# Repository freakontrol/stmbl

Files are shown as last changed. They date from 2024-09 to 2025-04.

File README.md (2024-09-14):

 

DISCLAIMER
===

THE AUTHORS OF THIS SOFTWARE ACCEPT ABSOLUTELY NO LIABILITY FOR
ANY HARM OR LOSS RESULTING FROM ITS USE.  IT IS _EXTREMELY_ UNWISE
TO RELY ON SOFTWARE ALONE FOR SAFETY.  Any machinery capable of
harming persons must have provisions for completely removing power
from all motors, etc, before persons enter any danger area.  All
machinery must be designed to comply with local and national safety
codes, and the authors of this software can not, and do not, take
any responsibility for such compliance.

This software is released under the GPLv3.

STMBL
=====

This Repository is a fork of the original project [STMBL](https://github.com/rene-dev/stmbl), an open-source servo drive designed for Retrofitting CNC machines and Robots. It supports Industrial AC and DC servos.

You can read the [documentation](https://freakontrol.github.io/stmbl/) to learn more about this project.

We are proposing a new revision of the project making significant improvements and updates:

- H-bridge
- Power connectors
- Bulk Capacitor
- Heat dissipation components and case
- Other obsolete components

 

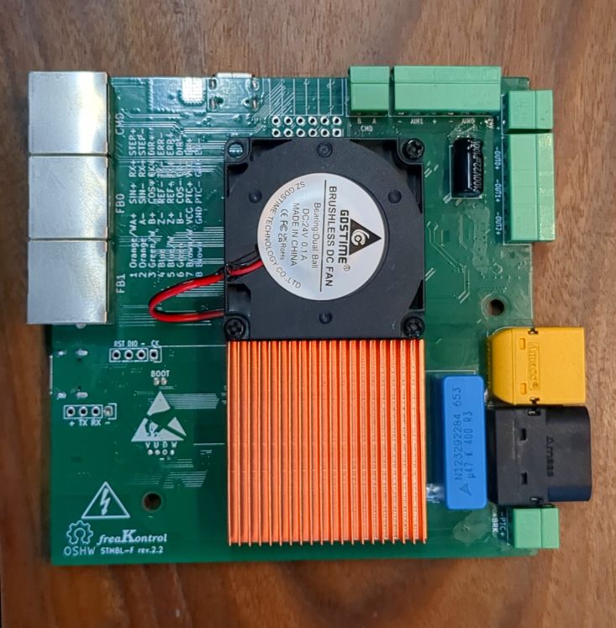
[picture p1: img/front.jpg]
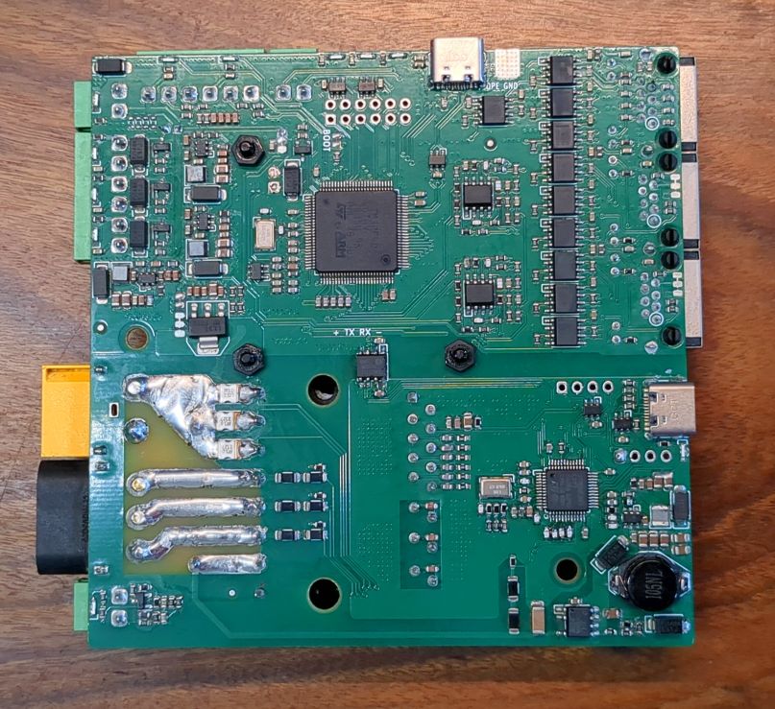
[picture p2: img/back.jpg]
  

## H-Bridge
First we needed to replace the original and obsolete H-bridge IRAM256 with a more powerful and easily available one.
We chose the [Infineon IKCM30F60GD](https://www.mouser.it/datasheet/2/196/Infineon_IKCM30F60GD_DataSheet_v02_05_EN-3361791.pdf) capable of peak output currents up to 60Amps instead of 30 of the original bridge.

## Upgrading Power connectors
During our tests with earlier prototypes we noticed that the original power connectors overheated and even got damaged when the board drove big loads.

 

So we decided to replace power connectors, both HV DC input and 3 Phase output with golden plated XT60PW and MR60PW connectors from Amass®, designed for high current up to 60Amps.

## Bulk Capacitor

We have relocated big bulk capacitors outside in a rectifier module as close as possible to the drives. 
Instead internally we kept a more compact MKP Polypropylene snubber capacitor for decoupling the bridge HV power supply.

 

## Heat dissipation components and case

We also optimized heat dissipation components and layout, reducing overall volume by half compared to the original design.

 
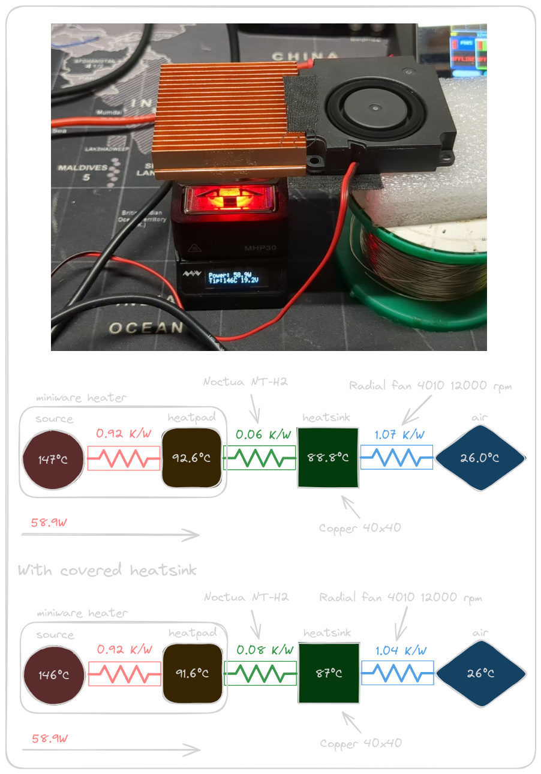
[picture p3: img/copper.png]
 

## Other obsolete components

there were several other components that have been replaced because they have become obsolete:

- ACT4088US-T (DC/DC converter) replaced with [RT8259GE](https://www.mouser.it/datasheet/2/1458/DS8259_03-3104661.pdf) from Richtek.
- With DC/DC converters, the power inductors have also been updated to:
    - [ME3220-472MLC 4.7uH ](https://www.mouser.it/ProductDetail/994-ME3220-472MLC)
    - [ME3220-682MLC 6.8uH](https://www.mouser.it/ProductDetail/994-ME3220-682MLC)
    - [ME3220-103KLC 10uH](https://www.mouser.it/ProductDetail/994-ME3220-103KLC)
- ZLDO1117G33TA (LDO 3.3V 1A) replaced with its new version [LDL1117S33R](https://www.mouser.it/ProductDetail/511-LDL1117S33R) from STMicroelettronics
- both microUSB connectors have been updated to the more modern USBc

* * * 
If you want to get a prototype of this board contact us [here](https://matrix.to/#/@stmbl:freakontrol.com).  
"Buy Me A Coffee" (https://www.buymeacoffee.com/freakontrol)

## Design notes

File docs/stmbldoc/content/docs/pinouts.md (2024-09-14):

---
title: "Pinouts"
weight: 5
# bookFlatSection: false
# bookToc: true
# bookHidden: false
# bookCollapseSection: false
# bookComments: false
# bookSearchExclude: false
---

## Pinouts

Interfaces:

* Mesa SmartSerial = full-duplex UART
* Encoder = QUAD
* Resolver = SIN/COS
* SSI, BiSS, EnDAT = half-duplex SPI
* Misu 02 = half-duplex UART
* Sanyo Denki = half-duplex UART
* Hyperface = SIN/COS + half-duplex UART

### Command connector wiring:

| Pin | Color | Smart Serial | Step/Dir | Quadrature  |
|-----|---|---|---|---|
| 1 | Orange Stripe | RX+ | Step+ | A+ |
| 2 | Orange | RX- | Step- | A- |
| 3 | Green Stripe | TX+ | Dir+ | B+ |
| 4 | Blue | | Err- | |
| 5 | Blue Stripe | | Err+ | |
| 6 | Green | TX- | Dir- | B- |
| 7 | Brown Stripe | | Enbl+ | |
| 8 | Brown | | Enbl- | |

### Feedback connector wiring - encoders etc

| Pin | Color | Resolver | Encoder | 1Vpp | UVW | Mitsubishi | Sanyo-Denki | Yaskawa | Omron  |
|-----|---|---|---|---|---|---|---|---|---|
| 1 | Orange Stripe | Sin+ | A+ | Sin+ | U+ | | | | |
| 2 | Orange | Sin- | A- | Sin- | U- | | | | |
| 3 | Green Stripe | Cos+ | B+ | Cos+ | V+ | | | | |
| 4 | Blue | Ref- | Z- | | W- | 2 | Blue | 6 | 4 |
| 5 | Blue Stripe | Ref+ | Z+ | | W+ | 1 | Brown | 5 | 7 |
| 6 | Green | Cos- | B- | Cos- | V- | | | | |
| 7 | Brown Stripe | AIN | VCC | VCC | VCC | VCC | Red | 1 | 6 |
| 8 | Brown | GND | GND | GND | GND | GND | Black | 2 | 3 |

### Connector wiring - serial protocols

| Pin | Color | RS485 | RS422 | UART | USART | UART HD  | USART HD | SPI | SPI HD |
|-----|---|---|---|---|---|---|---|---|---|
| 1 | Orange Stripe | | A | RX+ | RX+ | | | MISO+ | CS+ |
| 2 | Orange | | B | RX- | RX- | | | MISO- | CS- |
| 3 | Green Stripe | | | | CLK+ | | CLK+ | CLK+ | CLK+ |
| 4 | Blue | B | Z | TX- | TX- | TX/RX- | TX/RX- | MOSI- | MOSI- |
| 5 | Blue Stripe | A | Y | TX+ | TX+ | TX/RX+ | TX/RX+ | MOSI+ | MOSI+ |
| 6 | Green | | | | CLK- | | CLK- | CLK- | CLK- |
| 7 | Brown Stripe | VCC | VCC | VCC | VCC | VCC | VCC | VCC | VCC |
| 8 | Brown | GND | GND | GND | GND | GND | GND | GND | GND |

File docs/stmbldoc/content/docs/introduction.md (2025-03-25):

---
title: "Introduction"
weight: 1
# bookFlatSection: true
bookToc: true
# bookHidden: false
# bookCollapseSection: true
# bookComments: true
# bookSearchExclude: false
---

# STMBL Introduction Guide

## Description

STMBL is a motor drive controlled by the STM32 microprocessor. It can power motors of up to 2.2kW and up to around 380V DC bus voltage. The name "STMBL" is based on the combination of the STM32 microprocessor and BrushLess motor. However, the drive is also capable of powering AC induction or DC motors. The hardware is also capable of driving 3-phase stepper motors.

The drive is configurable for a wide range of command and feedback types through a hardware abstraction layer (HAL) analogous to that used by [LinuxCNC](http://linuxcnc.org/docs/2.7/html/hal/intro.html).

Currently supported command interfaces are:

* Mesa Smart-Serial  
* Quadrature, Step-Dir, Dir-Step, Up-Down ([enc cmd](/docs/hal_components/enc_cmd.md))  
* Usb Python interface  

Encoder power is 5V by default but 12V can be selected by jumper pads on the PCB.

In addition to motor control and dual feedback, each STMBL drive has two +/-30V analogue inputs and three 24V / 2A digital outputs.

To use the STMBL, you will need to:

* connect your command, feedback, and motor to STMBL using **suitable cables**.
* [Flash the firmware](/docs/introduction/#flashing-firmware)
* configure the drive for your motor using [Servoterm](/docs/getting_started/servoterm.md)
  * configure your [Feedback interface](/docs/getting_started/feedback.md)
  * find the correct [Motor parameters](/docs/getting_started/motor.md) for your motor
  * configure your [Command interface](/docs/getting_started/cmd.md)

## Anatomy of the STMBL

The STMBL consists of two separate PCBs that are made as one then assembled and split to be connected in the manner shown below. The vertical (top) board is the low-voltage (LV) board, and this handles the command, feedback, and configuration tasks. The STM32F405 microprocessor is in charge of these tasks.

The lower board is the high-voltage (HV) board, and this is where the power driver is situated. The only connection between the two boards is a serial connection through a 2.5kV isolation IC. To make this possible, there is a second STM32 chip on the lower board. This is an STM32F303 and is referred to as "F3" in the remainder of this document. The processor on the upper board is referred to as "F4".

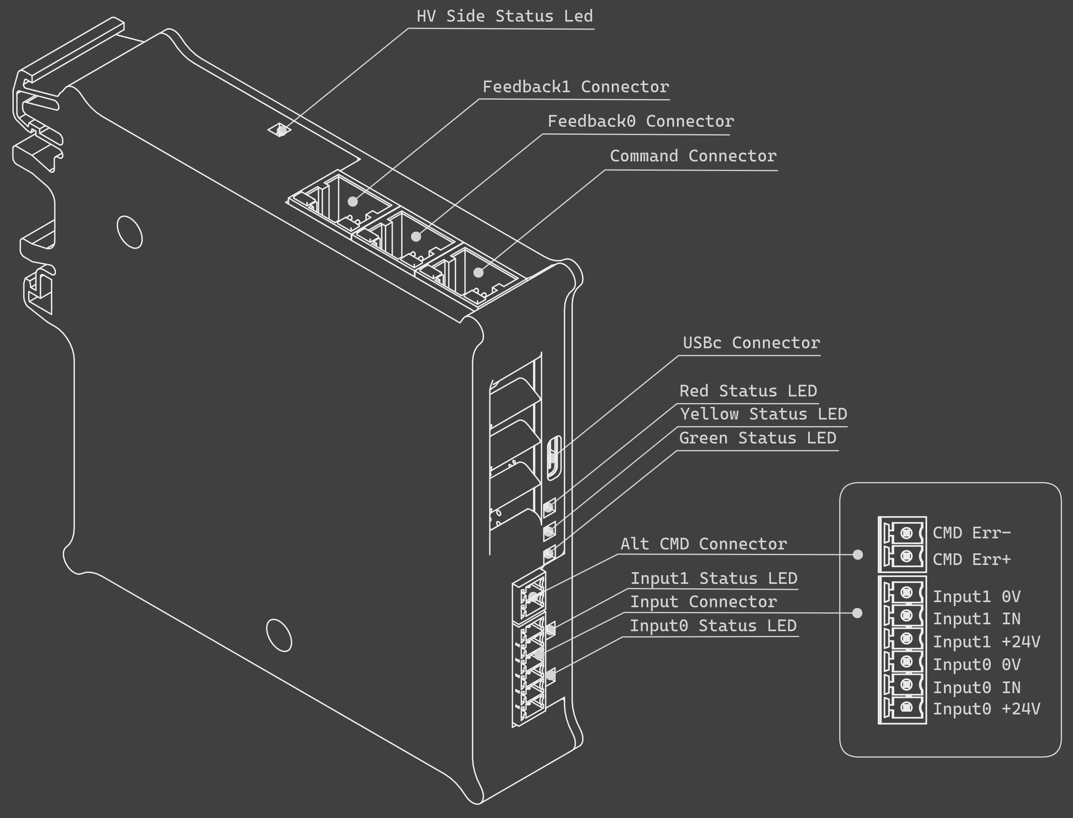
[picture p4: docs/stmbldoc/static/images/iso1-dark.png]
STMBL Anatomy


Logic power to the LV board should be 24V. A green LED will light adjacent to the socket when power is supplied.

{{% hint warning %}}
The LV board is safe up to about 26V but take care that 0V is common with the PC GND before connecting a USB cable.  
{{% /hint %}}

Motor power should be 30 to 350V, though the logic parts of the HV board may work at 24V for firmware flashing etc. Again, a green LED adjacent to the connector confirms that the board is powered-up.  

{{% hint warning %}}
The HV and LV boards are isolated in normal use but it is easy to accidentally connect them. One way to do this is via USB cables which can easily tie GND lines together through the setup PC.  
{{% /hint %}}  

{{% hint danger %}}
 It is imperative that the HV board should be powered from an isolated, low voltage supply when flashing firmware.
{{% /hint %}}  

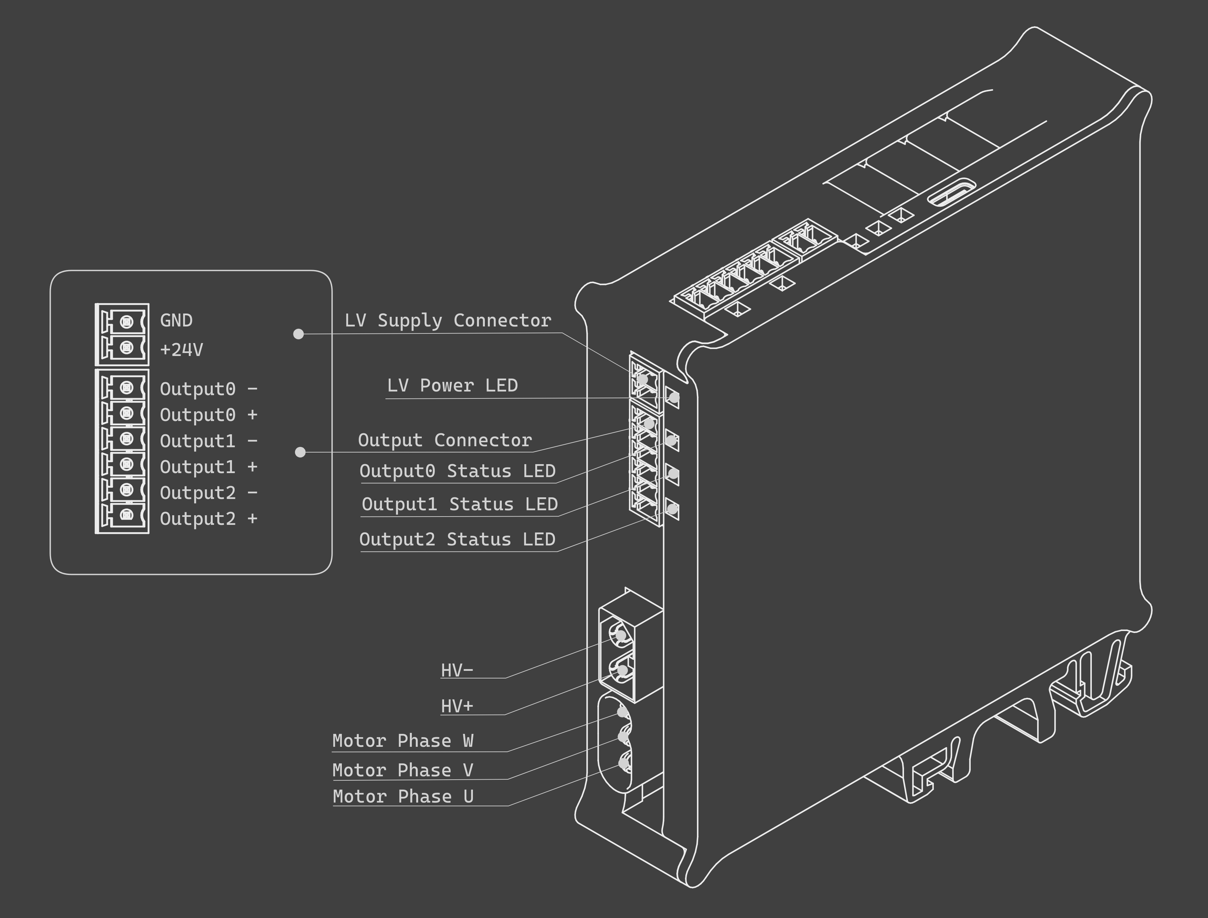
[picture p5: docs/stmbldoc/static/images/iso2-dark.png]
STMBL Connectors


The command and feedback connectors use standard 8P8C (RJ45) connectors and standard CAT5 or CAT6 cables can be conveniently used. To connect to cables with larger conductors than supported by CAT5, it is possible to use, for example, [Industrial CAT6a](https://octopart.com/j00026a2001-telegärtner-24873031) connectors which can accept core wires up to 1.6mm and overall cable diameters up to 9.0mm.

Feedback 0 will typically be the encoder or resolver mounted on the motor, and feedback 1 can be used to connect either Hall sensors for initial commutation or (potentially) scales mounted directly to the axes. See the [Pinouts](/docs/getting_started/pinouts) section of this document for pin assignments and typical wiring color codes.

The 6-way socket below the 24V logic power connector contains the three digital outputs. These are current-sinking (switch-to-GND) and each is adjacent to a 24V supply pin. DIO0 (nearest the top) is the one that is typically used to operate the holding brake on motors so-equipped.

On the top of the drive are two analog inputs, with 0V and 24V on either side to that an active sensors can be connected. These are typically used as variable-threshold digital inputs and are used, for example, for axis limit switches. However, it is relatively simple to configure them for other uses in the HAL.

Three LEDs on top of the unit indicate drive status. Red displays error codes (using [Blink Codes](/docs/errors/)). Amber indicates that all is well but the drive is not enabled, and green shows that the drive is active and operating normally. If no LEDs on the top of the board are illuminated, and the green power LEDs near the power connectors _are_ illuminated, then it is probably necessary to [flash the firmware](/docs/introduction/#flashing-firmware). If there are LEDs lit on top of the drive, then it is probably safe to assume that firmware is loaded.

## HAL (Hardware Abstraction Layer)

STMBL uses a data flow graph to configure the drive for different types of motor, feedback, and operation mode. This is conceptually similar to the HAL in [LinuxCNC](http://linuxcnc.org/docs/2.7/html/hal/intro.html), but the format and commands are different. Also, all pins are floating point so no data conversion is needed.  

Here is the graphical representation of the default configuration for the LV board and for the HV board

{{< zoomable-image src="/stmbl/graph/f4_festo_graph.dot.svg" alt="Low Voltage default hal config" >}}

{{< zoomable-image src="/stmbl/graph/hvf3_graph.dot.svg" alt="High Voltage default hal config" >}}  

An Application called [Servoterm](/docs/getting_started/servoterm/) is used to interact with the HAL interface and configure the drive. You will need to install and launch this before it is possible to configure the STMBL.

STMBL HAL configuration does not use any commands other than the = sign and the [Servoterm Commands](/docs/getting_started/servoterm/#servoterm-commands).

Assuming that there is already a motor connected to the drive and that the drive is powered up, the Servoterm display should already be indicating the motor position feedback. Rotating the motor shaft by hand might produce something like:

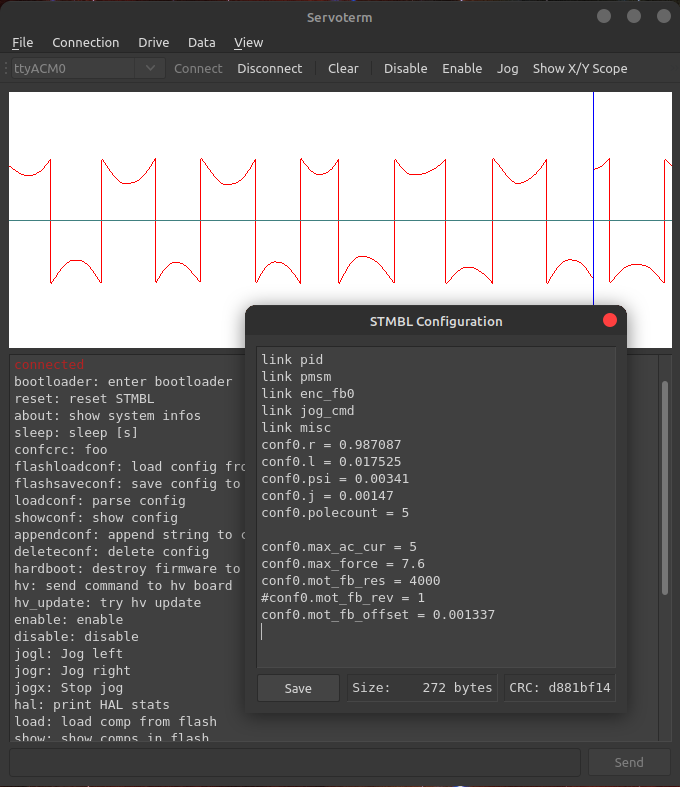
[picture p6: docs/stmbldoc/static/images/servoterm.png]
Servoterm Display


Though it equally well might not if the configuration is set up for a resolver and the motor has an encoder. It should be possible to make the motor turn at this point without any further configuration. The commands that follow will set the hv0 module up to simply rotate the motor open-loop in direct-mode (like a stepper motor) with an excitation current of 0.5A. This should be safe for most motors that the STMBL is a good match for, but you should choose your own value. For an explanation of direct and quadrature current, see the section on [Motor Basics](/docs/getting_started/motor/#motor-basics).

```
hv0.pos = sim0.vel
hv0.d_cmd = 0.5
hv0.en = 1
```

The rotation speed can be altered by changing the sim0 frequency:

```
sim0.freq = 5
```

STMBL HAL contains a number of components that have built-in linking behavior.

### Resolvers

Resolver phase - Setting the phase is very important to get resolver output. 'res0.phase = X' sets the phase. The number is between 0 and 1. Set for the highest output.

Resolver speed - In motor drives, resolver speed is typically 1. One rotation of the resolver equals one rotation of the motor. You will want to add these settings to the config so that the drive powers up with the settings as default.

### Motor pole count / setting motor feedback offset

Motor pole count in data sheets is often a total pole count rather than STMBL required 'pole pair' count. This is easy to see when running the com_test: type 'link com_test'. This should start the motor turning slowly in open loop, while displaying on the graph. Ideally, the green and black lines will match closely. If they are not the same speed (same number of peaks), then the motor poles setting is wrong. 'conf0.polecount' can be set without stopping the test. Set it till the number of green and black peaks are the same. Now the peaks may be offset on the graph. 'conf0.motor_fb_offset' will set this. Adjust this number till the black and green lines match. You'll want to add these settings to the config so the drive starts with these defaults.

### Jogging test

If you set the jogging checkbox at the top of ServoTerm and then enable the drive with: 'fault0.en = 1', using the left and right cursor keys on the keyboard can be used to jog the motor. The escape key will disable the drive quickly if something is not quite right. If there is a fault, then you will need to toggle the enable pin to 0 and back to 1 again. If the drive oscillates, try adjusting the 'conf0.j' setting for inertia.

### Drive the motor with a sine wave

1. Connect it `rev0.in = sim0.msin`
2. Set amplitude `sim0.amp = 1` (in rad)
3. Set frequency `sim0.freq = 0.5` (in Hz)
4. Enable `fault0.en = 1`

### Or constant velocity

1. Connect it `rev0.in = sim0.vel`
2. Set frequency `sim0.freq = 0.5` (in Hz)
3. Enable `fault0.en = 1`

Pressing Esc at any time will disable the drive. To reenable, press reset or type `fault0.en = 0` followed by `fault0.en = 1`.

### Components/templates/config list and examples  

You can find the list of components, template and configs in the Hal components, templates and configs section.  

## Flashing Firmware

### Requirements to build firmware

The GCC cross-compiler for Arm: gcc-arm-none-eabi-gcc [https://launchpad.net/gcc-arm-embedded/+download](https://launchpad.net/gcc-arm-embedded/+download) You will also need the STMBL source code, available from [https://github.com/freakontrol/stmbl](https://github.com/freakontrol/stmbl). You can either clone this as a [git](https://git-scm.com/) archive or just download a current snapshot as a zip file. In order for the STMBL Makefiles to be able to find the gcc binaries, you may need to create the file toolchain-user.mak to point to the correct folder and version number.

### Requirements to flash firmware

The STM32 chips have a built-in ROM bootloader, this means that it should be impossible to "brick" the boards. Each of the two CPUs in the STMBL drive needs both a dedicated bootloader to start the STMBL firmware and the firmware itself.

#### Linux/Unix

To flash the boards with USB, you will need the dfu-utils package [http://dfu-util.sourceforge.net](http://dfu-util.sourceforge.net). To flash the boards with a stlink programmer over SWD, you will need the stlink package [https://github.com/texane/stlink](https://github.com/texane/stlink)

#### Windows

You will need the STM Virtual Comport driver to connect with Servoterm [http://www.st.com/content/st_com/en/products/development-tools/software-development-tools/stm32-software-development-tools/stm32-utilities/stsw-stm32102.html](http://www.st.com/content/st_com/en/products/development-tools/software-development-tools/stm32-software-development-tools/stm32-utilities/stsw-stm32102.html) And the DfuSe USB device firmware upgrade STMicroelectronics extension to flash the firmware over USB [https://www.st.com/en/development-tools/stsw-stm32080.html](https://www.st.com/en/development-tools/stsw-stm32080.html)

### Checking for Existing Firmware - F4 board

Before flashing firmware, it is worth trying to figure out if your board is completely blank or has been pre-flashed with a bootloader or firmware. If the board will connect with Servoterm, then it already has a firmware and STMBL bootloader. "about" will show the firmware information of the F4 board. "hv about" will give the same information about the F3 board. Go to the [Updating Firmware](/docs/introduction/#updating-firmware) section to flash new firmware. If the board lights any LEDs other than the green power-good ones near to the power input connectors, then there is likely to already be a firmware installed. Go to the [Updating Firmware](/docs/introduction/#updating-firmware) section if you need to update the firmware. If the board is powered with 24V to the LV board and connected with USB to a PC, then it will report as "STMBL Virtual ComPort:" in the Apple System Profiler, "ID 0483:5740 STMicroelectronics STM32F407" in lsusb in Linux, and "STMBL Virtual COM Port" in the Windows device manager if there is a full firmware + STM32 bootloader installed. If the board shows "STM32 BOOTLOADER" (Mac), "0483:df11 STMicroelectronics STM Device in DFU Mode" (Linus lsusb), or "STM32 BOOTLOADER" (Windows Device Manager) when powered up (without using the boot pads), then this indicates that it already has an STMBL bootloader. (though no harm is done by re-flashing this) If the LV board does not show up at all on the USB bus, then attempt to put it in ROM boot mode by shorting the boot pads together while connecting the 24V. You should see "STM32 Bootlader" (Mac), "STMicroelectronics STM Device in DFU Mode" (Linux lsusb), or "STM32 BOOTLOADER" (Windows Device Manager) In this case, you will need to flash both the STMBL bootloader and the STMBL firmware. Go to the [Flashing the LV board with no bootloader](/docs/introduction/#flashing-the-lv-board-with-no-bootloader) section.

### Checking for existing firmware - F3 board

With 24V to the F3 board and with the F4 board _unpowered_, look at the red LED under the fan, near the USB connector. If the HV board has both an STMBL bootloader and an STMBL Firmware installed, then it will illuminate only the green power LED and will flash the red LED slowly to indicate no comms with the F4 board (which is why this check should be done with the F4 board unpowered). Go to the [Updating Firmware](/docs/introduction/#updating-firmware) section in this scenario. If the F3 board does not flash the red LED when the F4 is unpowered, then there is no bootloader and no firmware flashed. Go to the [Flashing the HV board with no bootloader](/docs/introduction/#flashing-the-hv-board-with-no-bootloader) section. If the F3 board has only a bootloader flashed and no or broken firmware, then the red LED will flash rapidly. Use the instructions in [Updating Firmware](/docs/introduction/#updating-firmware) in this case. The boards can also be flashed with a SWD programmer, but that process is not documented here. It can be convenient to flash the boards to test them before separating the halves and before installing the IRAM module and bus capacitors if you have a self-built or part-assembled board. Precompiled Binary versions of the firmware can be downloaded from [https://github.com/freakontrol/stmbl/releases](https://github.com/freakontrol/stmbl/releases) When compiling from the source code, firmware flashing is handled by specifying a makefile target for each of the firmware sections.

### Updating Firmware

The firmware on both the F3 and F4 board can be updated through the F4 USB port and without access to the boot pads. Connect 24V to both the F3 and F4 boards. In the source software folder, type `git pull` to get the latest software version. Type `make clean` to ensure that all files are freshened. Type `make` followed by `make binall` to create the binary files to be flashed. Type `make btburn` to program the F4 firmware and transfer a copy of the F3 software or type `make all_btburn` to program the F4 firmware + bootloader and transfer a copy of the F3 software 
{{% hint warning %}}
this will overwrite your config 
{{% /hint %}}  
There should then be a quantity of text output culminating with a progress bar like:

```
Downloading to address = 0x08000000, size = 2756
Download [=========================] 100% 2756 bytes
```

You can now re-connect with Servoterm and check the firmware version with `about`. Updating the F3 firmware is done via Servoterm using the `hv_update` command. This should give output similar to:

```
hv_update: SEND_TO_BOOTLOADER
hv_update: ERASE_FLASH
hv_update: SEND_APP
hv_update: status: 4%
...
hv_update: status: 95%
hv_update: CRC_CHECK
hv_update: status: 100%
hv_update: FLASH_SUCCESS
hv_update: status: 100%
hv_update: SLAVE_IN_APP
```

If this fails multiple times, go to the [Flashing the HV board with no bootloader](/docs/introduction/#flashing-the-hv-board-with-no-bootloader) section.

### Flashing the LV board with no bootloader

To flash the initial bootloader and firmware, it is necessary to put the STM32 CPU into ROM bootloader mode. You do this by shorting together the two pads marked "boot" on the LV board while connecting the 24V supply. This is a bit of a fiddle but should only need to be done once when the board is first built. For the exact location of these pads, see the illustration in the [Anatomy of the STMBL](/docs/introduction/#anatomy-of-the-stmbl) section. Typically, a small screwdriver can be used for this purpose. At this point, the board should appear as an "STM32 Bootloader" in the USB tree of the attached PC. Follow the [Updating Firmware](/docs/introduction/#updating-firmware) instructions and use the `make all_btburn` command.

### Flashing the HV board with no bootloader

Connect the USB cable to the HV board and short the boot pads on the HV board while connecting 24V to the HV input. To put it into bootloader mode. Again, it should appear in the USB device tree. Follow the [Updating Firmware](/docs/introduction/#updating-firmware) instructions but use the `make f3_all_btburn` command.

## linuxcnc

STMBL supports Mesa Smartserial to communicate with LinuxCNC. [http://linuxcnc.org/docs/html/man/man9/sserial.9.html](http://linuxcnc.org/docs/html/man/man9/sserial.9.html)

[https://www.youtube.com/watch?v=5CKMrOy0ZXk](https://www.youtube.com/watch?v=5CKMrOy0ZXk)

### STMBL config

At the end of your STMBL config, load sserial:

```
link sserial
```

Set the scale:

```
linrev0.scale = 5
```

#### Example: HAL config for Position mode with Position feedback

This is an example for one axis, Mesa 5i25 and one STMBL board, added to a .hal file in a machine config:

```
# This is an example for linuxcnc hal in position mode for the x-axis:
net xposcmd joint.0.motor-pos-cmd => hm2_5i25.0.stbl.0.0.pos_cmd
net xvelcmd joint.0.vel-cmd => hm2_5i25.0.stbl.0.0.vel_cmd
net xposfb joint.0.motor-pos-fb <= hm2_5i25.0.stbl.0.0.pos_fb
net xenable joint.0.amp-enable-out => hm2_5i25.0.stbl.0.0.enable
net xfault joint.0.amp-fault-in <= hm2_5i25.0.stbl.0.0.fault
net xindex joint.0.index-enable <=> hm2_5i25.0.stbl.0.0.index_enable
```

#### Example: Full Machine Config with STMBL boards, Mesa 7i80, Mesa 7i77, Analog Outputs, Encoder Inputs

See [https://github.com/aShure/cnc-configs/tree/master/justinbieber](https://github.com/aShure/cnc-configs/tree/master/justinbieber)

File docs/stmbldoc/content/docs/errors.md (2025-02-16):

---
title: "Errors"
weight: 7
# bookFlatSection: false
# bookToc: true
# bookHidden: false
# bookCollapseSection: false
# bookComments: false
# bookSearchExclude: false
---

# Blink Codes

## LV Side

### Normal Operation
   * No Error (Green LED on top illuminated. Good!)
   * Drive disabled (Yellow LED on top. Drive ready to go but disabled.)
   * Autophasing (Green and Yellow)
### Errors
   * Soft fault, resettable (Red LED blinks according to the list below)
   * Hard fault, bad! (All LEDs on top blink.)

Count the number of blinks of the red LED. Each number indicates a different class of faults.

 | LED Blink Times | Error                                 | Possible Solution                                          |
   |-----------------|-------------------------------------|------------------------------------------------------------|
   | 1               | Command Error                       | Common during setup. Only really relevant to smart-serial   |
   | 2               | Motor Feedback Error                | Verify motor feedback connections.         |
   | 3               | Commutation Feedback Error          | Check commutation feedback connections and configuration.    |
   | 4               | Joint Feedback Error                | Ensure joint feedback is properly connected and configured.|
   | 5               | Position Error                      | Review positioning mechanisms and settings.                |
   | 6               | Saturation Error                    | Adjust parameters to avoid saturation.                     |
   | 7               | Motor temperature high              | Check for overheating issues or motor ptc misconfiguration.   |
   | 8               | HV Side serial CRC Error           | Ensure data integrity during communication with the side.|
   | 9               | HV Side comms Timeout Error        | HV side is not powered or programmed correctly.             |
   | 10              | HV Side over-temperature           | Check the fan, air intake/output obstruction or dust in the heatsink.  |
   | 11              | HV Voltage out of range             | Check if power supply is stable and if the dynamic braking circuit is working. |
   | 12              | HV Side Fault                      | Investigate specific faults reported by the HV side.      |
   | 13              | HV current offset fault             | Damaged F3 micro ADC?            |
   | 14              | HV Overcurrent RMS                  | Reduce average current consumption to stay within limits.  |
   | 15              | HV Overcurrent Peak                 | Limit peak current spikes to prevent overcurrent issues.   |
   | 16              | HV Overcurrent HW                   | The motor power size is too high (or the bridge is broken) |

## HV Side

### Normal operation
   * Green LED at power input
### Errors
   * Red LED blinks fast - Bootloader but no or broken firmware
   * Red LED blinks slow - No communication with F4
   * Red LED does not blink _AND_ F4 not plugged in - No firmware or bootloader

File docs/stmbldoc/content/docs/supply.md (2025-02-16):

---
title: "Supply"
weight: 6
# bookFlatSection: false
# bookToc: true
# bookHidden: false
# bookCollapseSection: false
# bookComments: false
# bookSearchExclude: false
---

 # Power Supply Requirements for STMBL Board

The STMBL board is designed to operate with a specific range of voltage and current for its various components. Understanding these requirements is crucial for proper operation and safety. This page provides an overview of the power supply requirements for the STMBL board, including information about the big electrolitic capacitors needed in the power supply close to the HV board.

## Power Supply Specifications

The following table summarizes the power supply specifications for the STMBL board:

### PCB Version 5

| Connector | Abs. MIN | MIN | TYP | MAX | Abs. MAX | Unit | Note |
|---|---|-----|-----|-----|---|---|---|
| 24V | 0 | 15  | 24  | 25  | 26 | V | |
| 24V | | | 0.2 | 3 | 6 | A | 1 |
| HV | 0 | 24  | 320 | 380 | 400 | V | |
| HV | -28 | -17 | | 17  | 28 | A | 2 |
| CMD | -7 | 0 | | 5 | 12 | V | |
| CMD | -250 | -50 | | 50  | 250 | mA | |
| FB VPP | 0 | 0 | | 12  | 24 | V | |
| FB VPP | 0 | 0 | 500 | 1000| 1500 | mA | |
| FB diff.  | -7 | 0 | | 5 | 12 | V | |
| FB diff.  | | -1.2| | +1.2| | Vpp  | 3 |
| FB | -250 | -50 | | 50  | 250 | mA | |
| output | 0 | 0 | | 24  | 26 | V | |
| output | 0 | 0 | | 1 | 2 | A | |
| input | -36 | -24 | | 24  | 36 | V | |
| IO | 0 | 0 | | 5 | 5 | V | |
| UVW | 0 | 0 | | 380 | 400 | V | |
| UVW | -30 | -58 | | 58  | 60 | A | |
| UVW avg.  | | -27 | | 27  | | A | 2 |

*Note 1: Depends on brake, fan and encoder consumption*  
*Note 2: Depends on PCB and driver cooling*  
*Note 3: For analog input*

## Big Electrolitic Capacitors

The STMBL board requires the use of big electrolitic capacitors in its power supply, particularly close to the HV board. These capacitors are essential for filtering and stabilizing the high-voltage power supply, ensuring smooth operation and reducing electrical noise. The specific capacitance values may vary depending on the exact application and motor load. It is recommended to consult the STMBL documentation or a qualified engineer for the most accurate capacitor selection.

## Safety Considerations

When working with high-voltage components like the STMBL board, it is crucial to prioritize safety. Always follow proper installation and usage guidelines, and ensure that all connections are secure and properly insulated. Never attempt to operate the board without the necessary power supply or motor load connected. In case of any doubts or concerns about the power supply requirements, consult a qualified engineer or refer to the official STMBL documentation for further guidance.

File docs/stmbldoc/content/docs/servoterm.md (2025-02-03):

---
title: "Servoterm"
weight: 3
# bookFlatSection: false
# bookToc: true
# bookHidden: false
# bookCollapseSection: false
# bookComments: false
# bookSearchExclude: false
---

# Servoterm

Servoterm (servo terminal) provides an interface which allows editing of the drive HAL configuration. It also provides a rolling graphical representation of any chosen parameter in the HAL, which can be a great aid to tuning and motor setup.

Servoterm is now available as a C++ application. You can download it from [this GitHub repository](https://github.com/STMBL/QtServoterm).

## Installation

To install Servoterm, follow these steps:

1. Clone the repository:
   ```sh
   git clone https://github.com/STMBL/QtServoterm.git
   ```

2. Navigate to the project directory:
   ```sh
   cd QtServoterm
   ```

3. Build the application using qmake and make:
   ```sh
   qmake
   make
   ```

4. Run the application:
   ```sh
   ./Servoterm
   ```

## Connecting to STMBL

To connect to the STMBL, you will need a mini-USB B cable. 
{{% hint danger %}}
Be sure that the 24V PSU is floating or shares a ground reference with the PC.  
(Maybe even check the voltage between the connector and socket before inserting the plug.)
{{% /hint %}}  
You can then click the "connect" button and you should get something like the image below.  

## Servoterm Interface

Taking the buttons from left to right:

* Connect / Disconnect - Should be fairly self-evident
* Clear - simply clears the screen
* Reset - Reenables the drive and clears faults. Does not reset the STMBL. To do that type the [Servoterm Commands](#servoterm-commands), `reset`
* Capture - Allows the output of the graphs to be saved and exported as CSV. First click starts the recording, second click stops and saves the file.
* Jog - when ticked the left-right arrow keys on the keyboard can be used to jog the motor.
* Trigger - stops the graph plot until the trigger condition is met.
* Trigger Status Indicator - not a button
* Edit Config - Brings up a sub-window in which the basic system config can be edited.

Other than the buttons described above, the remainder of Servoterm (and the STMBL HAL) is controlled by a command-line interface at the bottom. Servoterm uses the up and down arrow keys to scroll through previous commands, but there is no tab-completion. This is mainly described in the [HAL](#hal-hardware-abstraction-layer) section of this document. The graphing display is controlled by the "term0" interface. Typing `term0` at the prompt will show output similar to:

Servoterm Terminal Interface

The first two entries are internal information about the HAL component and can be ignored for now. The next 8 lines say what internal signal each of the wave plots is connected to. In this case, wave0 (the black one) is connected to a sim signal, in this case, the sine wave. (as you might have guessed, typing "sim0" will show you the parameters of the simulated signals.) To connect wave1 (red) to the sawtooth output (which simulates both encoder feedback and a position command for steady rotation), then simply type `term0.wave1 = sim0.vel`. Each wave has an associated offset and gain parameter that can be used to adjust vertical scale and position. The `term0.send_step` parameter functions like the time-base of an oscilloscope.

## Servoterm Commands

The Servoterm command list can be obtained at the command line by using the `help` command. Commands to be used by the user:

* bootloader: enter bootloader
* reset: reset STMBL
* about: show system infos
* help: print this
* link: load config template
* hal: print HAL stats
* hv_update: update the F3 firmware
* show_config: show config templates
* show: show comps in flash
* list: show comp instances
* hv FOOBAR XYZ: send "FOOBAR XYZ" to the HV board

Commands for internal use:

* confcrc: Shows the CRC checksum of the loaded config.
* flashloadconf: load config from flash
* flashsaveconf: save config to flash
* loadconf: parse config
* showconf: show config - pressing the `Edit config` button is better.
* appendconf: append string to config - also redundant with the config editor
* deleteconf: delete config
* load: load comp from flash
* start: start rt system
* stop: stop rt system
* fault: trigger fault

## Servoterm Connection Problems

If you encounter connection issues, ensure that your serial setup is correct. Here are some steps to troubleshoot:

1. **Check Serial Port**: Ensure that the correct serial port is selected in Servoterm.
2. **Ground Reference**: Make sure that the 24V PSU is floating or shares a ground reference with the PC.
3. **USB Cable**: Use a good quality mini-USB B cable to connect the STMBL to your computer.

Linux/Mac? Add your username to the dialout group to be able to access the com ports. If you have used the Arduino IDE before, this is probably already set:

```
sudo usermod -a -G dialout username

```

Linux udev rules:

```
SUBSYSTEM=="usb", ACTION!="add", GOTO="objdev_rules_end"
#stmbl
ATTR{idVendor}=="0483", ATTR{idProduct}=="5740", ENV{ID_MM_DEVICE_IGNORE}="1", GROUP="users", MODE="0666"
#ST USB bootloader
ATTR{idVendor}=="0483", ATTR{idProduct}=="df11", GROUP="users", MODE="0666"
LABEL="objdev_rules_end"

```

If you get AT commands showing up in servoterm some application is sending commands to the virtual serial port despite the `ENV{ID_MM_DEVICE_IGNORE}="1"` above. For example on xfce with debian 10, ModemManager may need to be stopped with `systemctl disable ModemManager.service` or removed with `sudo apt-get purge modemmanager`

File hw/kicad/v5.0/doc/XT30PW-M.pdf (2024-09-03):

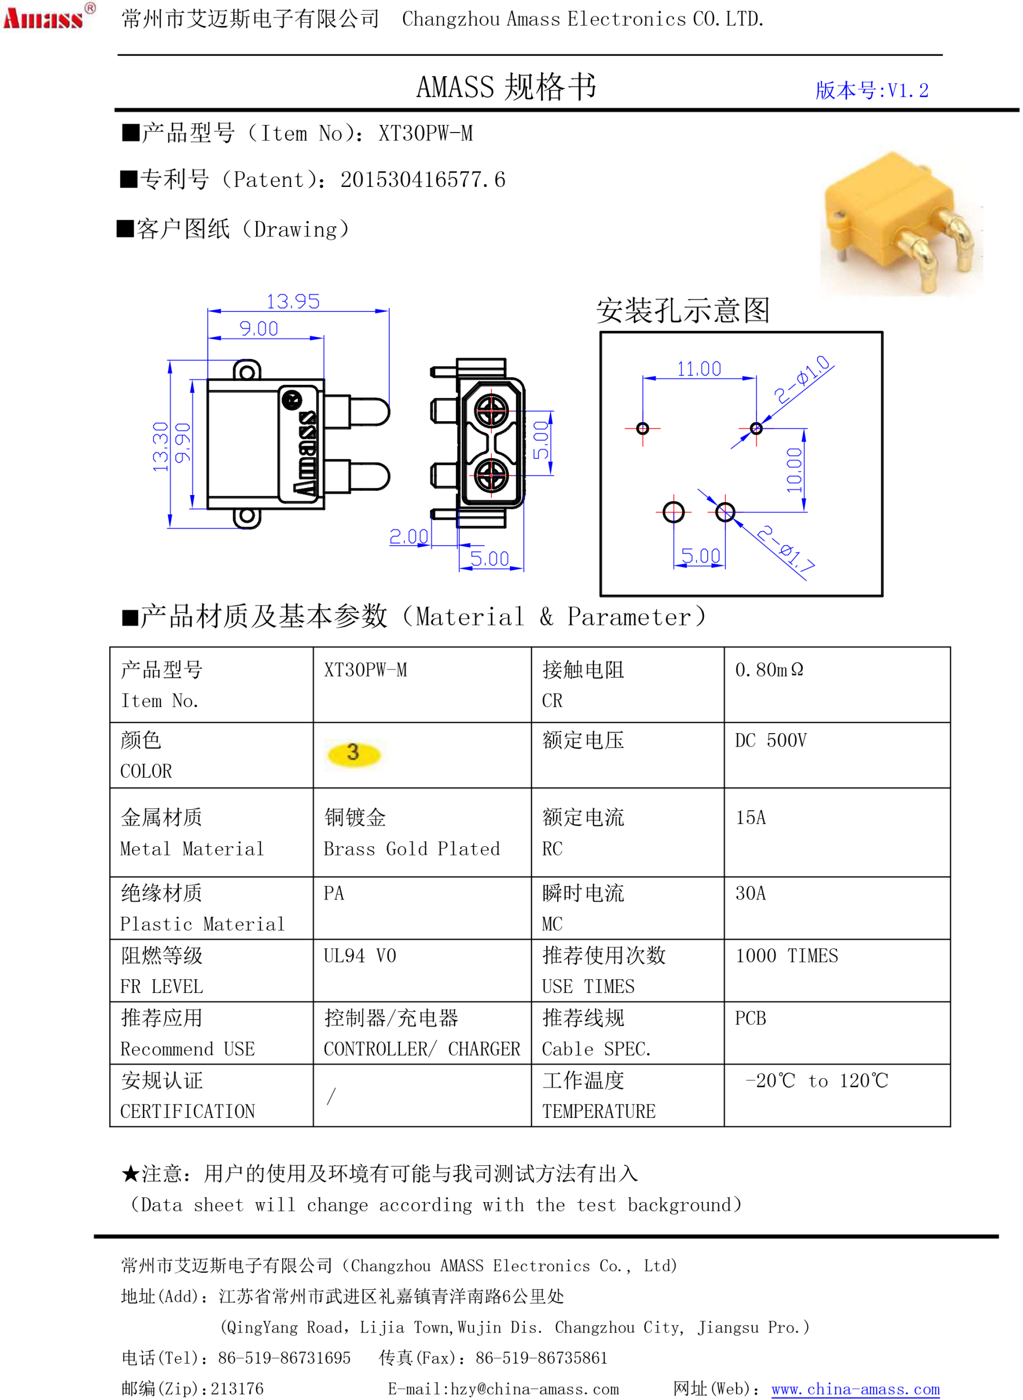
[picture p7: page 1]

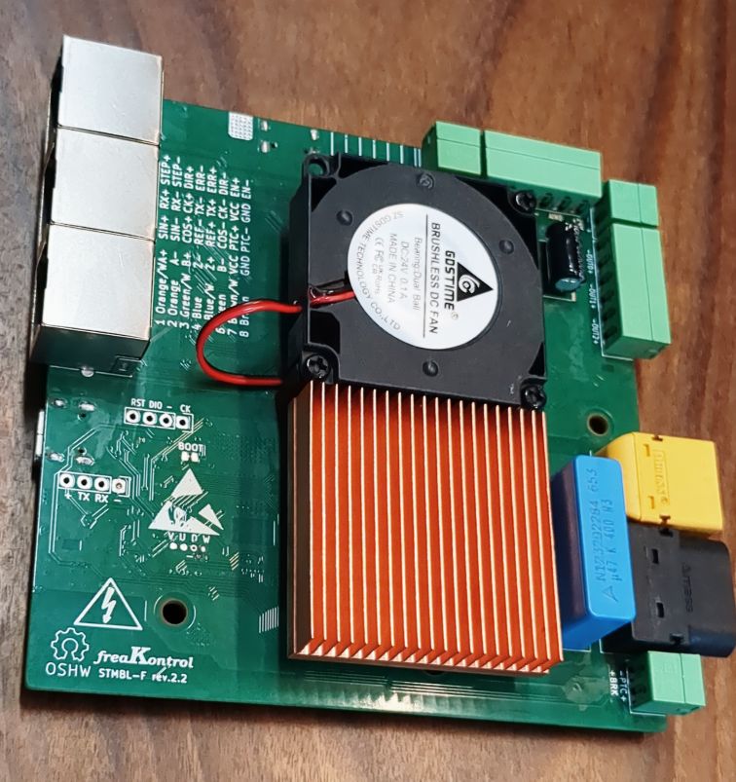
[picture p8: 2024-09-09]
img/front2.jpg

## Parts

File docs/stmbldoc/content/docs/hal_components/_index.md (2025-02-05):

---
bookCollapseSection: true
weight: 2
redirect_to: "/docs/hal_components/ac/"
---

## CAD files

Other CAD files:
mechanics/stmbl_case_industrial.FCStd

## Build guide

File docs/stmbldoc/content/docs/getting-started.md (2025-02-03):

---
title: "Getting Started"
weight: -1
# bookFlatSection: true
bookToc: true
# bookHidden: false
# bookCollapseSection: true
# bookComments: true
# bookSearchExclude: false
---

# STMBL Getting Started Guide

## Description

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

Currently supported command interfaces are:

* Mesa Smart-Serial
* Step-Dir
* Quadrature
* Serial

+/-10V control is not supported, though the hardware capability exists.

Currently supported feedback interfaces are:

* Encoder
* Resolver
* sin/cos 1vpp
* Hall sensors
* Mitsubishi absolute encoder
* Yaskawa absolute encoder
* Sanyo Denki absolute encoder
* Fanuc serial encoder

The hardware has the capability to support other protocols like:

* EnDat
* BiSS
* SSI
* Modbus
* Profibus
* Hiperface
* CANopen

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

To use the STMBL, you will need to:

* connect your command, feedback, and motor to STMBL using **suitable cables**.
* [Flash the firmware](getting-started.md/#flashing-firmware)
* configure the drive for your motor using [Servoterm](servoterm.md)
  * configure your [Feedback interface](configuration/feedback.md)
  * find the correct [Motor parameters](configuration/motor.md) for your motor
  * configure your [Command interface](configuration/cmd.md)

## Anatomy of the STMBL

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

STMBL Anatomy

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

STMBL Connectors

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

Feedback 0 will typically be the encoder or resolver mounted on the motor, and feedback 1 can be used to connect either Hall sensors for initial commutation or (potentially) scales mounted directly to the axes. See the [Pinouts](#pinouts) section of this document for pin assignments and typical wiring color codes.

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

Three LEDs on top of the unit indicate drive status. Red displays error codes (using [Blink Codes](#blink-codes)). Amber indicates that all is well but the drive is not enabled, and green shows that the drive is active and operating normally. If no LEDs on the top of the board are illuminated, and the green power LEDs near the power connectors _are_ illuminated, then it is probably necessary to [flash the firmware](#flashing-firmware). If there are LEDs lit on top of the drive, then it is probably safe to assume that firmware is loaded.

## HAL (Hardware Abstraction Layer)

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

An Application called [Servoterm](#servoterm) is used to interact with the HAL interface and configure the drive. You will need to install and launch this before it is possible to configure the STMBL.

STMBL HAL configuration does not use any commands other than the = sign and the [Servoterm Commands](#servoterm-commands).

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

Servoterm Display

Though it equally well might not if the configuration is set up for a resolver and the motor has an encoder. It should be possible to make the motor turn at this point without any further configuration. The commands that follow will set the hv0 module up to simply rotate the motor open-loop in direct-mode (like a stepper motor) with an excitation current of 0.5A. This should be safe for most motors that the STMBL is a good match for, but you should choose your own value. For an explanation of direct and quadrature current, see the section on [Motor Basics](#motor-basics).

```
hv0.pos = sim0.vel
hv0.d_cmd = 0.5
hv0.en = 1
```

The rotation speed can be altered by changing the sim0 frequency:

```
sim0.freq = 5
```

STMBL HAL contains a number of components that have built-in linking behavior.

### Resolvers

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

### Motor pole count / setting motor feedback offset

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

### Jogging test

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

### Drive the motor with a sine wave

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

### Or constant velocity

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

## Flashing Firmware

### Requirements to build firmware

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

### Requirements to flash firmware

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

#### Linux/Unix

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

#### Windows

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

### Checking for Existing Firmware - F4 board

Before flashing firmware, it is worth trying to figure out if your board is completely blank or has been pre-flashed with a bootloader or firmware. If the board will connect with Servoterm, then it already has a firmware and STMBL bootloader. "about" will show the firmware information of the F4 board. "hv about" will give the same information about the F3 board. Go to the [Updating Firmware](#updating-firmware) section to flash new firmware. If the board lights any LEDs other than the green power-good ones near to the power input connectors, then there is likely to already be a firmware installed. Go to the [Updating Firmware](#updating-firmware) section if you need to update the firmware. If the board is powered with 24V to the LV board and connected with USB to a PC, then it will report as "STMBL Virtual ComPort:" in the Apple System Profiler, "ID 0483:5740 STMicroelectronics STM32F407" in lsusb in Linux, and "STMBL Virtual COM Port" in the Windows device manager if there is a full firmware + STM32 bootloader installed. If the board shows "STM32 BOOTLOADER" (Mac), "0483:df11 STMicroelectronics STM Device in DFU Mode" (Linus lsusb), or "STM32 BOOTLOADER" (Windows Device Manager) when powered up (without using the boot pads), then this indicates that it already has an STMBL bootloader. (though no harm is done by re-flashing this) If the LV board does not show up at all on the USB bus, then attempt to put it in ROM boot mode by shorting the boot pads together while connecting the 24V. You should see "STM32 Bootlader" (Mac), "STMicroelectronics STM Device in DFU Mode" (Linux lsusb), or "STM32 BOOTLOADER" (Windows Device Manager) In this case, you will need to flash both the STMBL bootloader and the STMBL firmware. Go to the [Flashing the LV board with no bootloader](#flashing-the-lv-board-with-no-bootloader) section.

### Checking for existing firmware - F3 board

With 24V to the F3 board and with the F4 board _unpowered_, look at the red LED under the fan, near the USB connector. If the HV board has both an STMBL bootloader and an STMBL Firmware installed, then it will illuminate only the green power LED and will flash the red LED slowly to indicate no comms with the F4 board (which is why this check should be done with the F4 board unpowered). Go to the [Updating Firmware](#updating-firmware) section in this scenario. If the F3 board does not flash the red LED when the F4 is unpowered, then there is no bootloader and no firmware flashed. Go to the [Flashing the HV board with no bootloader](#flashing-the-hv-board-with-no-bootloader) section. If the F3 board has only a bootloader flashed and no or broken firmware, then the red LED will flash rapidly. Use the instructions in [Updating Firmware](#updating-firmware) in this case. The boards can also be flashed with a SWD programmer, but that process is not documented here. It can be convenient to flash the boards to test them before separating the halves and before installing the IRAM module and bus capacitors if you have a self-built or part-assembled board. Precompiled Binary versions of the firmware can be downloaded from [https://github.com/freakontrol/stmbl/releases](https://github.com/freakontrol/stmbl/releases) When compiling from the source code, firmware flashing is handled by specifying a makefile target for each of the firmware sections.

### Updating Firmware

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

```
Downloading to address = 0x08000000, size = 2756
Download [=========================] 100% 2756 bytes
```

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

```
hv_update: SEND_TO_BOOTLOADER
hv_update: ERASE_FLASH
hv_update: SEND_APP
hv_update: status: 4%
...
hv_update: status: 95%
hv_update: CRC_CHECK
hv_update: status: 100%
hv_update: FLASH_SUCCESS
hv_update: status: 100%
hv_update: SLAVE_IN_APP
```

If this fails multiple times, go to the [Flashing the HV board with no bootloader](#flashing-the-hv-board-with-no-bootloader) section.

### Flashing the LV board with no bootloader

To flash the initial bootloader and firmware, it is necessary to put the STM32 CPU into ROM bootloader mode. You do this by shorting together the two pads marked "boot" on the LV board while connecting the 24V supply. This is a bit of a fiddle but should only need to be done once when the board is first built. For the exact location of these pads, see the illustration in the [Anatomy of the STMBL](#anatomy-of-the-stmbl) section. Typically, a small screwdriver can be used for this purpose. At this point, the board should appear as an "STM32 Bootloader" in the USB tree of the attached PC. Follow the [Updating Firmware](#updating-firmware) instructions and use the `make all_btburn` command.

### Flashing the HV board with no bootloader

Connect the USB cable to the HV board and short the boot pads on the HV board while connecting 24V to the HV input. To put it into bootloader mode. Again, it should appear in the USB device tree. Follow the [Updating Firmware](#updating-firmware) instructions but use the `make f3_all_btburn` command.

## linuxcnc

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

[https://www.youtube.com/watch?v=5CKMrOy0ZXk](https://www.youtube.com/watch?v=5CKMrOy0ZXk)

### STMBL config

At the end of your STMBL config, load sserial:

```
link sserial
```

Set the scale:

```
linrev0.scale = 5
```

#### Example: HAL config for Position mode with Position feedback

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

```
# This is an example for linuxcnc hal in position mode for the x-axis:
net xposcmd joint.0.motor-pos-cmd => hm2_5i25.0.stbl.0.0.pos_cmd
net xvelcmd joint.0.vel-cmd => hm2_5i25.0.stbl.0.0.vel_cmd
net xposfb joint.0.motor-pos-fb <= hm2_5i25.0.stbl.0.0.pos_fb
net xenable joint.0.amp-enable-out => hm2_5i25.0.stbl.0.0.enable
net xfault joint.0.amp-fault-in <= hm2_5i25.0.stbl.0.0.fault
net xindex joint.0.index-enable <=> hm2_5i25.0.stbl.0.0.index_enable
```

#### Example: Full Machine Config with STMBL boards, Mesa 7i80, Mesa 7i77, Analog Outputs, Encoder Inputs

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

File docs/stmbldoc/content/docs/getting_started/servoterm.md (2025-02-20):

---
title: "Servoterm"
weight: 2
# bookFlatSection: false
# bookToc: true
# bookHidden: false
# bookCollapseSection: false
# bookComments: false
# bookSearchExclude: false
---

# Servoterm

Servoterm (servo terminal) provides an interface which allows editing of the drive HAL configuration. It also provides a rolling graphical representation of any chosen parameter in the HAL, which can be a great aid to tuning and motor setup.

Servoterm is now available as a C++ application. You can download it from [this GitHub repository](https://github.com/STMBL/QtServoterm).  

## Installation

To install Servoterm, follow these steps:

1. Clone the repository:
   ```sh
   git clone https://github.com/STMBL/QtServoterm.git
   ```

2. Navigate to the project directory:
   ```sh
   cd QtServoterm
   ```

3. Build the application using qmake and make (you need to install first the required dependencies based on your system):
   ```sh
   qmake
   make
   ```

4. Run the application:
   ```sh
   ./Servoterm
   ```

## Connecting to STMBL

To connect to the STMBL, you will need a USB C cable. 
{{% hint danger %}}
Be sure that the 24V PSU is floating or shares a ground reference with the PC.  
(Maybe even check the voltage between the connector and socket before inserting the plug.)
{{% /hint %}}  
You can then click the "connect" button and you should get something like the image below.  

Servoterm Terminal Interface

## Servoterm Interface

Taking the buttons from left to right:

* **Connect** / **Disconnect** (Connection) - Should be fairly self-evident
* **Clear** - simply clears the screen
* **Disable** / **Enable** (Drive) - Reenables the drive and clears faults. Does not reset the STMBL. To do that type the [Servoterm Commands](/docs/getting_started/servoterm/#servoterm-commands), `reset`
* **Record** (Data) - Under Data menu, it allows the output of the graphs to be saved and exported as CSV.
* **Jog** (Drive) - when ticked the left-right arrow keys on the keyboard can be used to jog the motor.
* **Show X/Y Scope** (View) - This shows or hides the XY scope in the graph side.
* **Config** (Drive) - Brings up a sub-window in which the basic system config can be edited.

Other than the buttons described above, the remainder of Servoterm (and the STMBL HAL) is controlled by a command-line interface at the bottom. Servoterm uses the up and down arrow keys to scroll through previous commands, but there is no tab-completion. This is mainly described in the [HAL](/docs/introduction/#hal-hardware-abstraction-layer) section. The graphing display is controlled by the "term0" interface. Typing `term0` at the prompt will show output similar to:

```ini
term0.rt_prio = 16.000000
term0.frt_prio = 0.000000
term0.wave0 <= reslimit0.pos_out = 0.000000
term0.wave1 <= fb_switch0.plot_fb_pos = -0.000785
term0.wave2 <= vel0.vel = 0.000000
term0.wave3 <= vel1.vel = 0.000000
term0.wave4 = 0.000000
term0.wave5 = 0.000000
term0.wave6 = 0.000000
term0.wave7 = 0.000000
term0.offset0 = 0.000000
term0.offset1 = 0.000000
term0.offset2 = 0.000000
term0.offset3 = 0.000000
term0.offset4 = 0.000000
term0.offset5 = 0.000000
term0.offset6 = 0.000000
term0.offset7 = 0.000000
term0.gain0 = 20.000000
term0.gain1 = 20.000000
term0.gain2 = 1.000000
term0.gain3 = 1.000000
term0.gain4 = 10.000000
term0.gain5 = 10.000000
term0.gain6 = 10.000000
term0.gain7 = 10.000000
term0.send_step = 50.000000
term0.con = 1.000000
```  

The first two entries are internal information about the HAL component and can be ignored for now. The next 8 lines say what internal signal each of the wave plots is connected to. In this case, wave0 (the black one) is connected to a sim signal, in this case, the sine wave. (as you might have guessed, typing "sim0" will show you the parameters of the simulated signals.) To connect wave1 (red) to the sawtooth output (which simulates both encoder feedback and a position command for steady rotation), then simply type `term0.wave1 = sim0.vel`. Each wave has an associated offset and gain parameter that can be used to adjust vertical scale and position. The `term0.send_step` parameter functions like the time-base of an oscilloscope.

## Servoterm Commands

The Servoterm command list can be obtained at the command line by using the `help` command. Commands to be used by the user:

* `bootloader`: enter bootloader
* `reset`: reset STMBL
* `about`: show system infos
* `help`: print this
* `link`: load config template
* `hal`: print HAL stats
* `hv_update`: update the F3 firmware
* `show_config`: show config templates
* `show`: show comps in flash
* `list`: show comp instances
* `hv FOOBAR XYZ`: send "FOOBAR XYZ" to the HV board

Commands for internal use:

* `confcrc`: Shows the CRC checksum of the loaded config.
* `flashloadconf`: load config from flash
* `flashsaveconf`: save config to flash
* `loadconf`: parse config
* `showconf`: show config - pressing the `Config` button is better.
* `appendconf`: append string to config - also redundant with the config editor
* `deleteconf`: delete config
* `load`: load comp from flash
* `start`: start rt system
* `stop`: stop rt system
* `fault`: trigger fault

## Servoterm Connection Problems

If you encounter connection issues, ensure that your serial setup is correct. Here are some steps to troubleshoot:

1. **Check Serial Port**: Ensure that the correct serial port is selected in Servoterm.
2. **Ground Reference**: Make sure that the 24V PSU is floating or shares a ground reference with the PC.
3. **USB Cable**: Use a good quality USB C cable to connect the STMBL to your computer.

Linux/Mac? Add your username to the dialout group to be able to access the com ports. If you have used the Arduino IDE before, this is probably already set:

```
sudo usermod -a -G dialout username

```

Linux udev rules:

```sh
SUBSYSTEM=="usb", ACTION!="add", GOTO="objdev_rules_end"
#stmbl
ATTR{idVendor}=="0483", ATTR{idProduct}=="5740", ENV{ID_MM_DEVICE_IGNORE}="1", GROUP="users", MODE="0666"
#ST USB bootloader
ATTR{idVendor}=="0483", ATTR{idProduct}=="df11", GROUP="users", MODE="0666"
LABEL="objdev_rules_end"

```

If you get AT commands showing up in servoterm some application is sending commands to the virtual serial port despite the `ENV{ID_MM_DEVICE_IGNORE}="1"` above. For example on xfce with debian 10, ModemManager may need to be stopped with `systemctl disable ModemManager.service` or removed with `sudo apt-get purge modemmanager`

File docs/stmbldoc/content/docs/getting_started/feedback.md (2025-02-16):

---
title: "Feedback"
weight: 3
# bookFlatSection: false
# bookToc: true
# bookHidden: false
# bookCollapseSection: false
# bookComments: false
# bookSearchExclude: false
---

# Feedback

## Incremental Encoder  

 An [incremental encoder](https://en.wikipedia.org/wiki/Incremental_encoder) operates on the principle of quadrature encoding, meaning it uses two channels of data to provide accurate measurement information. When the encoder is rotated or displaced, both output signals A and B change in a specific sequence that indicates direction and magnitude of movement. However, since it doesn't maintain an absolute position reference, it only provides relative changes from its initial state.  

### STMBL FBx Pinout

| Pin | Signal |
|-----|---|
| 1 | A+ |
| 2 | A- |
| 3 | B+ |
| 4 | Z- (optional) |
| 5 | Z+ (optional) |
| 6 | B- |
| 7 | VCC |
| 8 | GND |

### Config

```python
link enc_fb0
conf0.mot_fb_res = 4096
```

## Sin/Cos Encoder  

 A [sin-cos encoder](https://electronics.stackexchange.com/a/187115) is a type of rotary encoder that outputs two signals, sine and cosine waves, which are phase-shifted by 90 degrees. These signals can be used to determine the position and direction of rotation with high precision. The encoder generates these signals based on the angular position of its shaft relative to a datum point. By comparing the values of the sine and cosine outputs at any given time, it's possible to calculate the exact angle or position of the shaft.  

### STMBL FBx Pinout

| Pin | Signal |
|-----|---|
| 1 | Sin+ |
| 2 | Sin- |
| 3 | Cos+ |
| 4 | Ref- (optional) |
| 5 | Ref+ (optional) |
| 6 | Cos- |
| 7 | VCC |
| 8 | GND |

### Config

```python
link enc_fb0
conf0.mot_fb_res = 4096
fb_switch0.mot_pos = enc_fb0.ipos
```

## Resolver  

 A [resolver](https://en.wikipedia.org/wiki/Resolver_(electrical)) is an electrical device that converts the angular position of a rotating shaft into an output signal by using magnetic fields and coils. It generates two phase-shifted sine signals that can be used to determine the position and direction of rotation with high precision.  

### STMBL FBx Pinout

| Pin | Signal |
|-----|---|
| 1 | Sin+ |
| 2 | Sin- |
| 3 | Cos+ |
| 4 | Ref- (optional) |
| 5 | Ref+ (optional) |
| 6 | Cos- |
| 7 | AIN |
| 8 | GND |

### Config

```python
link res_fb0
```

## Tamagawa Smartabs
```
 _____
|2 4 6\
|1_3_5/
```

### Cable pinout

| Pin | Signal |
|---|---|
| Red | Vcc |
| Black | Gnd |
| Brown | Bat+ |
| Brown/Black | Bat- |
| Blue | D+ |
| Blue/Black  | D- |
| Gray | CASE GND |
| Shield | NC |

### STMBL FBx Pinout

| Pin | Signal |
|-----|---|
| 1 | |
| 2 | |
| 3 | |
| 4 | Blue/Black |
| 5 | Blue |
| 6 | |
| 7 | Red |
| 8 | Black |

### Config

```python
link smartabs_fb0
```

## Mitsubishi

Mitsubishi servos such HA-FF usually have OBA17-051 or OBA17-052 encoders.

STMBL has support the "mit 02-4" and "mit 02-2" protocols for these encoders.  

* [some protocol description](https://github.com/freakontrol/stmbl/blob/main/src/comps/encm.c#L114 )  

### STMBL FBx Pinout

| Pin | Signal |
|-----|---|
| 1 | |
| 2 | |
| 3 | |
| 4 | 2 |
| 5 | 1 |
| 6 | |
| 7 | VCC |
| 8 | GND |

### Config

```python
link encm_fb0
```

## Kawasaki - Sanyo Denki absolute encoder

### STMBL FBx Pinout

| Pin | Signal |
|-----|---|
| 1 | |
| 2 | |
| 3 | |
| 4 | Blue |
| 5 | Brown |
| 6 | |
| 7 | Red |
| 8 | Black |

### Config

```python
link encs_fb0
```

## Omron absolute encoder

### Cable pinout
```
 _________
| 4 3 2 1 |
 \_7_6_5_/
 ```

| Pin | Signal |
|-----|---|
| 1 | Shield |
| 2 | Bat- |
| 3 | GND |
| 4 | D- |
| 5 | BAT+ |
| 6 | 5v |
| 7 | D+ |

### STMBL FBx Pinout

| Pin | Signal |
|-----|---|
| 1 | |
| 2 | |
| 3 | |
| 4 | 4 |
| 5 | 7 |
| 6 | |
| 7 | 6 |
| 8 | 3 |

### Config

## Panasonic absolute encoder

### Cable pinout
```
 _____
|1 2 3|
|4_5_6|
```

| Pin | Signal |
|-----|---|
| 1 | NC |
| 2 | D+ |
| 3 | D- |
| 4 | 5v |
| 5 | GND |
| 6 | Shield |

### STMBL FBx Pinout

| Pin | Signal |
|-----|---|
| 1 | |
| 2 | |
| 3 | |
| 4 | 3 |
| 5 | 2 |
| 6 | |
| 7 | 4 |
| 8 | 5 |

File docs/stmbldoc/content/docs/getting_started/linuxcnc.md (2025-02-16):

---
title: "Linuxcnc"
weight: 6
# bookFlatSection: false
# bookToc: true
# bookHidden: false
# bookCollapseSection: false
# bookComments: false
# bookSearchExclude: false
---

# LinuxCNC

Here an example of linuxcnc configuration using smart serial.

## Hal file

```c++
loadrt [KINS]KINEMATICS
loadrt [EMCMOT]EMCMOT servo_period_nsec=[EMCMOT]SERVO_PERIOD num_joints=[KINS]JOINTS
loadrt hostmot2
loadrt [HOSTMOT2](DRIVER) config=[HOSTMOT2](CONFIG)
loadrt estop_latch

setp    hm2_[HOSTMOT2](BOARD).0.watchdog.timeout_ns 50000000

addf hm2_[HOSTMOT2](BOARD).0.read         servo-thread
addf motion-command-handler               servo-thread
addf motion-controller                    servo-thread
addf hm2_[HOSTMOT2](BOARD).0.write        servo-thread
addf estop-latch.0                        servo-thread

net xposcmd joint.0.motor-pos-cmd  => hm2_[HOSTMOT2](BOARD).0.stbl.0.0.pos_cmd
net xvelcmd joint.0.vel-cmd        => hm2_[HOSTMOT2](BOARD).0.stbl.0.0.vel_cmd
net xposfb  joint.0.motor-pos-fb  <=  hm2_[HOSTMOT2](BOARD).0.stbl.0.0.pos_fb
net xenable joint.0.amp-enable-out => hm2_[HOSTMOT2](BOARD).0.stbl.0.0.enable
net xfault  joint.0.amp-fault-in  <=  hm2_[HOSTMOT2](BOARD).0.stbl.0.0.fault
#net xindex  joint.0.index-enable  <=> hm2_[HOSTMOT2](BOARD).0.stbl.0.0.index_enable
setp hm2_[HOSTMOT2](BOARD).0.stbl.0.0.scale 6

# A basic estop loop that only includes the hostmot watchdog.
net user-enable iocontrol.0.user-request-enable => estop-latch.0.reset
net enable-latch estop-latch.0.ok-out => iocontrol.0.emc-enable-in
net watchdog hm2_[HOSTMOT2](BOARD).0.watchdog.has_bit => estop-latch.0.fault-in

# create signals for tool loading loopback
net tool-prep-loop iocontrol.0.tool-prepare => iocontrol.0.tool-prepared
net tool-change-loop iocontrol.0.tool-change => iocontrol.0.tool-changed

```

## INI file

```ini
[EMC]
VERSION = 1.1
MACHINE = stmbl
DEBUG = 0

[DISPLAY]
DISPLAY =              axis
CYCLE_TIME =            0.0500
POSITION_OFFSET =       RELATIVE
POSITION_FEEDBACK =     ACTUAL
MAX_FEED_OVERRIDE =     1.5
PROGRAM_PREFIX = ../../nc_files/
INTRO_GRAPHIC =         linuxcnc.gif
INTRO_TIME =            5
MAX_LINEAR_VELOCITY = 100
MAX_ANGULAR_VELOCITY = 50

[RS274NGC]
PARAMETER_FILE =        stmbl.var

[EMCMOT]
EMCMOT =                motmod
COMM_TIMEOUT =          1.0
SERVO_PERIOD =          1000000

[TASK]
TASK =                  milltask
CYCLE_TIME =            0.010

[HAL]
HALFILE = stmbl.hal

[HALUI]
#No Content

[TRAJ]
COORDINATES =           X Y Z
LINEAR_UNITS =          mm
ANGULAR_UNITS =         degree

[EMCIO]
EMCIO =                 io
CYCLE_TIME =            0.100
TOOL_TABLE =            tool.tbl

[KINS]
KINEMATICS = trivkins
JOINTS = 3

[AXIS_X]
MIN_LIMIT = -1000.0
MAX_LIMIT = 1000.0
MAX_VELOCITY = 100
MAX_ACCELERATION = 20

[AXIS_Y]
MIN_LIMIT = -1000.0
MAX_LIMIT = 1000.0
MAX_VELOCITY = 100
MAX_ACCELERATION = 20

[AXIS_Z]
MIN_LIMIT = -1000.0
MAX_LIMIT = 1000.0
MAX_VELOCITY = 100
MAX_ACCELERATION = 20

[JOINT_0]
TYPE =              LINEAR
MAX_VELOCITY =       50
MAX_ACCELERATION =   100
BACKLASH =           0.000
MIN_LIMIT =             -1000.0
MAX_LIMIT =             1000.0
FERROR =     1
MIN_FERROR = 1
#HOME =                  0.000
#HOME_OFFSET =           0.10
#HOME_SEARCH_VEL =       0.10
#HOME_LATCH_VEL =        -0.01
#HOME_USE_INDEX =        YES
#HOME_IGNORE_LIMITS =    YES
HOME_SEQUENCE =         1

[JOINT_1]
TYPE =              LINEAR
MAX_VELOCITY =       50
MAX_ACCELERATION =   100
BACKLASH =           0.000
MIN_LIMIT =             -1000.0
MAX_LIMIT =             1000.0
FERROR =     1
MIN_FERROR = 1
#HOME =                  0.000
#HOME_OFFSET =           0.10
#HOME_SEARCH_VEL =       0.10
#HOME_LATCH_VEL =        -0.01
#HOME_USE_INDEX =        YES
#HOME_IGNORE_LIMITS =    YES
HOME_SEQUENCE =         1

[JOINT_2]
TYPE =              LINEAR
MAX_VELOCITY =      50
MAX_ACCELERATION =  100
BACKLASH =           0.000
MIN_LIMIT =             -1000.0
MAX_LIMIT =             1000.0
FERROR =     1
MIN_FERROR = 1
#HOME =                  0.000
#HOME_OFFSET =           0.10
#HOME_SEARCH_VEL =       0.10
#HOME_LATCH_VEL =        -0.01
#HOME_USE_INDEX =        YES
#HOME_IGNORE_LIMITS =    YES
HOME_SEQUENCE =         0

[HOSTMOT2]
DRIVER=hm2_eth board_ip="192.168.1.121"
BOARD=7i92
CONFIG="num_encoders=0 num_pwmgens=0 num_stepgens=0 sserial_port_0=00000000"
```

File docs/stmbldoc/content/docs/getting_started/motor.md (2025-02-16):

---
title: "Motor"
weight: 4
# bookFlatSection: false
# bookToc: true
# bookHidden: false
# bookCollapseSection: false
# bookComments: false
# bookSearchExclude: false
---

# Motor

{{% hint info %}}
Is possible to use the [Autotuning](/docs/getting_started/tuning.md) to estimate the motor parameters.  
You can still use this guide if the autotuning fail.  
{{% /hint %}} 

## Motor parameters

Unfortunately, servo motor datasheets often lack a good description of the parameters. There is a difference between line-to-line and phase values. Here are listed the most important motor parameters and how to determine them.  

### Resistance (conf0.r)

1. Measure line-to-line resistance R
2. Convert to phase resistance conf0.r = R/2

### Inductance (conf0.l)

1. Measure line-to-line inductance L
2. Convert to phase inductance conf0.l = L/2

If you can't measure this, set it to 0.001/(phase resistance).

### Moment of Inertia (conf0.j)

1. Read moment of inertia from datasheet

### Pole Pair Count (conf0.polecount)

1. Attach a power supply to the motor (limit the current)
2. Turn the motor one rotation and count the number N of positions it snaps in conf0.polecount = N

### Torque Constant (conf0.psi)

The default value works for most motors. Normally, you don't have to measure this! There is no common ground for the torque constant. Some manufacturers state the current in RMS, others in peak-to-peak. We also stumbled over values that were neither. How to determine psi:

#### Scope

1. Drive motor at constant speed (lathe, power drill, ...)
2. Connect an oscilloscope between two phases and measure frequency F (Hz) and peak, line-to-line voltage U0 (V)
3. Convert to line-to-neutral voltage U1 = U0/sqrt(3)
4. Convert to amplitude U2 = U1/2
5. Convert to torque constant conf0.psi = U2/F/2.0/PI

#### STMBL

It's also possible to measure psi directly with STMBL. Maybe even automatically in a future version.

1. Disconnect the HV power, leave the servo connected.
2. Connect with Servoterm, drag&drop this file into Servoterm: [https://github.com/freakontrol/stmbl/blob/master/conf/template/psi.txt](https://github.com/freakontrol/stmbl/blob/master/conf/template/psi.txt)
3. Type `stop` and `start`
4. Turn the shaft of the motor. You can use your hand for a rough estimation, but it's probably better to drive with a cordless drill. The closer to the nominal RPM rating, the more accurate the result will be. There is no need to turn the shaft continuously, a quick short turn of one revolution is sufficient.
5. Type `psi0.max_psi` and you will get the peak psi value that was measured. You can set `conf0.psi` to the measured peak psi value now. If you did not drive the motor reasonably fast, the proper psi value is probably a couple percent higher.

#### KV

psi = 60.0 / #POLE_PAIRS / sqrt(3) / 2.0 / PI / KV

#### Nm/A

psi = (Nm/A) / 3.0 \* 2.0 / #POLE_PAIRS

#### PID

The default values work for most motors. Normally, you don't have to tune this. The STMBL PID works differently than common PID loops. Understand the [code](https://github.com/freakontrol/stmbl/blob/master/shared/comps/pid.c) and its interaction with the [motor model](https://github.com/freakontrol/stmbl/blob/master/shared/comps/pmsm_limits.c) first!

* conf0.pos_p position pid proportional gain (1/s)
* conf0.vel_p velocity pid proportional gain (1/s)
* conf0.vel_i velocity pid integral gain
* conf0.cur_p current pid proportional gain (V/A)
* conf0.cur_i current pid integral gain
* conf0.cur_ff current pid resistance feedforward gain
* conf0.cur_ind current pid BEMF feedforward gain

#### Command

* conf0.cmd_rev command reverse
* conf0.cmd_res command resolution (1/rev)

#### Limits

Exceeding a limit results in an action.

* conf0.max_dc_volt voltage limit (V): disable drive
* conf0.high_dc_volt brake resistor limit (V) : activate brake resistor (Note: there is no built-in brake resistor in STMBL V3 or V4)
* conf0.low_dc_volt voltage limit (V): disable drive
* conf0.max_hv_temp temperature limit (°C): disable drive
* conf0.high_hv_temp temperature limit (°C): reduce max current
* conf0.fan_hv_temp temperature limit (°C): activate fan
* conf0.max_pos_error max position error (rad): disable drive
* conf0.max_sat max saturation time (s): disable drive

## Config

### DC motor

```python
link dc
```

### PMSM motor

```python
link pmsm
```

### ASYNC motor

```python
link acim
```

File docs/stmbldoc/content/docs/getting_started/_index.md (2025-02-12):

---
weight: 2
# bookFlatSection: true
# bookToc: true
# bookHidden: false
bookCollapseSection: true
redirect_to: "/docs/getting_started/first_steps/"
# bookComments: true
# bookSearchExclude: false
---

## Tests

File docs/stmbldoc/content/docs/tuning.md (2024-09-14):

---
title: "Tuning"
weight: 4
# bookFlatSection: false
# bookToc: true
# bookHidden: false
# bookCollapseSection: false
# bookComments: false
# bookSearchExclude: false
---

# Parameter Tuning

## Requirements

* [Supply](configuration/supply.md)
* [Servoterm](servoterm.md)
* [Feedback](configuration/feedback.md)
* [Motor](configuration/motor.md)

## Electrical Parameters

### DC Motor

#### Manual Tuning

```python
conf0.r # motor phase resistance
conf0.l # motor phase inductance
conf0.psi # torque constant [Nm/A] or [V/rad/s]
conf0.mot_fb_rev
```

#### Auto Tuning

This takes about 20 seconds. Disconnect the motor from the load. The motor will turn with a max velocity of `iddc0.test_vel (rad/s)` and apply a max current of `iddc0.test_cur (A)`. Follow the green instructions in Servoterm:

- Set your config to:

```python
link pid
link dc
link <your_feedback_type>
link misc
link id_dc
```

- Reset STMBL by typing:

```python
reset
```

- Start the tuning by typing:

```python
fault0.en = 1
```

- Lock the rotor and type:

```python
iddc0.state = 1.2
```

- Unlock the rotor and type:

```python
iddc0.state = 2.2
```

- Append the result (`conf0.r`, `conf0.l`, `conf0.psi`, opt. `conf0.out_rev`) to your config.
- Go to [Motor Mechanical Parameters](#motor-mechanical-parameters).

### PMSM Motor

#### Manual Tuning

```python
conf0.r # motor phase resistance
conf0.l # motor phase inductance
conf0.polecount # number of pole pairs
conf0.mot_fb_offset
conf0.out_rev
conf0.psi # torque constant [Nm/A] or [V/rad/s]
```

#### Auto Tuning

This takes about 20 seconds. Disconnect the motor from the load. The motor will turn with a max velocity of `idpmsm0.test_vel (rad/s)` and apply a max current of `idpmsm0.test_cur (A)`. Follow the green instructions in Servoterm:

- Set your config to:

```python
link pid
link pmsm
link <your_feedback_type>
link misc
link id_pmsm
```

- Reset STMBL by typing:

```python
reset
```

- Start the tuning by typing:

```python
fault0.en = 1
```

- Append the result (`conf0.r`, `conf0.l`, `conf0.psi`, `conf0.polecount`, `conf0.mot_fb_offset`, opt. `conf0.out_rev`) to your config.
- Go to [Motor Mechanical Parameters](#motor-mechanical-parameters).

## Motor Mechanical Parameters

### Manual Tuning

```python
conf0.j
```

### Auto Tuning

This takes about 2 minutes. Disconnect the motor from the load. The motor will move between `idm0.min_pos (rad)` and `idm0.max_pos (rad)` with a max velocity of `idm0.max_vel (rad/s)` and a max acceleration of `idm0.max_acc (rad/s^2)`. Follow the green instructions in Servoterm:

- Set your config to:

```python
link pid
link <your_motor_type>
link <your_feedback_type>
link misc
link id_mot
<your_electrical_parameters>
```

- Reset STMBL by typing:

```python
reset
```

- Start the tuning by typing:

```python
fault0.en = 1
```

- Append the result (`conf0.j`, `conf0.d`, `conf0.f`, `conf0.o`) to your config.
- Go to [System Mechanical Parameters](#system-mechanical-parameters).

## System Mechanical Parameters

You can skip this step if you want to tune the motor without load.

### Manual Tuning

```python
conf0.j_sys
conf0.j_lpf
```

### Auto Tuning

This takes about 2 minutes. Connect the motor to the load. The motor will move between `idm0.min_pos (rad)` and `idm0.max_pos (rad)` with a max velocity of `idm0.max_vel (rad/s)` and a max acceleration of `idm0.max_acc (rad/s^2)`. Follow the green instructions in Servoterm:

- Set your config to:

```python
link pid
link <your_motor_type>
link <your_feedback_type>
link misc
link id_sys
<your_electrical_parameters>
<your_mechanical_parameters>
```

- Reset STMBL by typing:

```python
reset
```

- Start the tuning by typing:

```python
fault0.en = 1
```

- Append the result (`conf0.j_sys`, `conf0.d`, `conf0.f`, `conf0.o`) to your config.
- Go to [Control Loop Tuning](#control-loop-tuning).

## Control Loop Tuning

### Manual Tuning

```python
conf0.pos_bw
conf0.vel_bw
conf0.vel_d
```

### Auto Tuning

This takes about 2 minutes. Connect the motor to the load. The motor will move between `ids0.min_pos (rad)` and `ids0.max_pos (rad)` with a max velocity of `ids0.max_vel (rad/s)` and a max acceleration of `ids0.max_acc (rad/s^2)`. Follow the green instructions in Servoterm:

- Set your config to:

```python
link pid
link <your_motor_type>
link <your_feedback_type>
link misc
link id_pid
<your_electrical_parameters>
<your_mechanical_parameters>
```

- Reset STMBL by typing:

```python
reset
```

- Start the tuning by typing:

```python
fault0.en = 1
```

- Append the result (`conf0.pos_bw`, `conf0.vel_bw`, `conf0.vel_d`) to your config.
- Go to [Cmd](configuration/cmd.md).

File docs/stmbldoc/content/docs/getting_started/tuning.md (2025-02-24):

---
title: "Tuning"
weight: 5
# bookFlatSection: false
# bookToc: true
# bookHidden: false
# bookCollapseSection: false
# bookComments: false
# bookSearchExclude: false
---

# Parameter Tuning

## Requirements

* [Supply](/docs/supply.md)
* [Servoterm](/docs/getting_started/servoterm.md)
* [Feedback](/docs/getting_started/feedback.md)
* [Motor](/docs/getting_started/motor.md)

## Electrical Parameters

### DC Motor

#### Manual Tuning

```python
conf0.r # motor phase resistance
conf0.l # motor phase inductance
conf0.psi # torque constant [Nm/A] or [V/rad/s]
conf0.mot_fb_rev
```

#### Auto Tuning

This takes about 20 seconds. Disconnect the motor from the load. The motor will turn with a max velocity of `iddc0.test_vel (rad/s)` and apply a max current of `iddc0.test_cur (A)`. Follow the green instructions in Servoterm:

- Set your config to:

```python
link pid
link dc
link <your_feedback_type>
link misc
link id_dc
```

- Reset STMBL by typing:

```python
reset
```

- Start the tuning by typing:

```python
fault0.en = 1
```

- Lock the rotor and type:

```python
iddc0.state = 1.2
```

- Unlock the rotor and type:

```python
iddc0.state = 2.2
```

- Append the result (`conf0.r`, `conf0.l`, `conf0.psi`, opt. `conf0.out_rev`) to your config.
- Go to [Motor Mechanical Parameters](/docs/getting_started/tuning#motor-mechanical-parameters).

### PMSM Motor

#### Manual Tuning

```python
conf0.r # motor phase resistance
conf0.l # motor phase inductance
conf0.polecount # number of pole pairs
conf0.mot_fb_offset
conf0.out_rev
conf0.psi # torque constant [Nm/A] or [V/rad/s]
```

#### Auto Tuning

This takes about 20 seconds. Disconnect the motor from the load. The motor will turn with a max velocity of `idpmsm0.test_vel (rad/s)` and apply a max current of `idpmsm0.test_cur (A)`. Follow the green instructions in Servoterm:

- Set your config to:

```python
link pid
link pmsm
link <your_feedback_type>
link misc
link id_pmsm
```

- Reset STMBL by typing:

```python
reset
```

- Start the tuning by typing:

```python
fault0.en = 1
```

- Append the result (`conf0.r`, `conf0.l`, `conf0.psi`, `conf0.polecount`, `conf0.mot_fb_offset`, opt. `conf0.out_rev`) to your config.
- Go to [Motor Mechanical Parameters](/docs/getting_started/tuning#motor-mechanical-parameters).

## Motor Mechanical Parameters

### Manual Tuning

```python
conf0.j
```

### Auto Tuning

This takes about 2 minutes. Disconnect the motor from the load. The motor will move between `idm0.min_pos (rad)` and `idm0.max_pos (rad)` with a max velocity of `idm0.max_vel (rad/s)` and a max acceleration of `idm0.max_acc (rad/s^2)`. Follow the green instructions in Servoterm:

- Set your config to:

```python
link pid
link <your_motor_type>
link <your_feedback_type>
link misc
link id_mot
<your_electrical_parameters>
```

- Reset STMBL by typing:

```python
reset
```

- Start the tuning by typing:

```python
fault0.en = 1
```

- Append the result (`conf0.j`, `conf0.d`, `conf0.f`, `conf0.o`) to your config.
- Go to [System Mechanical Parameters](/docs/getting_started/tuning#system-mechanical-parameters).

## System Mechanical Parameters

You can skip this step if you want to tune the motor without load.

### Manual Tuning

```python
conf0.j_sys
conf0.j_lpf
```

### Auto Tuning

This takes about 2 minutes. Connect the motor to the load. The motor will move between `idm0.min_pos (rad)` and `idm0.max_pos (rad)` with a max velocity of `idm0.max_vel (rad/s)` and a max acceleration of `idm0.max_acc (rad/s^2)`. Follow the green instructions in Servoterm:

- Set your config to:

```python
link pid
link <your_motor_type>
link <your_feedback_type>
link misc
link id_sys
<your_electrical_parameters>
<your_mechanical_parameters>
```

- Reset STMBL by typing:

```python
reset
```

- Start the tuning by typing:

```python
fault0.en = 1
```

- Append the result (`conf0.j_sys`, `conf0.d`, `conf0.f`, `conf0.o`) to your config.
- Go to [Control Loop Tuning](/docs/getting_started/tuning#control-loop-tuning).

## Control Loop Tuning

### Manual Tuning

```python
conf0.pos_bw
conf0.vel_bw
conf0.vel_d
```

### Auto Tuning

This takes about 2 minutes. Connect the motor to the load. The motor will move between `ids0.min_pos (rad)` and `ids0.max_pos (rad)` with a max velocity of `ids0.max_vel (rad/s)` and a max acceleration of `ids0.max_acc (rad/s^2)`. Follow the green instructions in Servoterm:

- Set your config to:

```python
link pid
link <your_motor_type>
link <your_feedback_type>
link misc
link id_pid
<your_electrical_parameters>
<your_mechanical_parameters>
```

- Reset STMBL by typing:

```python
reset
```

- Start the tuning by typing:

```python
fault0.en = 1
```

- Append the result (`conf0.pos_bw`, `conf0.vel_bw`, `conf0.vel_d`) to your config.
- Go to [Cmd](/docs/getting_started/cmd.md).

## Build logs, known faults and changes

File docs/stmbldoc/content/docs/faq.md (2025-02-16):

---
title: "FAQ"
weight: 8
# bookFlatSection: false
# bookToc: true
# bookHidden: false
# bookCollapseSection: true
# bookComments: false
# bookSearchExclude: false
---

### How to contact the devs?
- https://matrix.to/#/@stmbl:freakontrol.com
- https://gitter.im/rene-dev/stmbl
- https://webirc.hackint.org/#stmbl or #stmbl on irc.hackint.eu
### Does it work with DC Servos?
Yes, but DC servos usually operate at a much lower voltage, and the IGBT module we use is not very efficient at low voltages.
### Does it work with stepper motors?
No.
### Why do you use 2 CPUs?
The driver is designed to run of rectified mains, without a transformer. Therefore the high voltage side has to be fully isolated. Here we need to supply about 8 digital I/Os, and measure many analog values. The cheapest way of doing this is to use a second CPU, and only isolate a UART. The communication is running at 3Mbit, but 9Mbit is possible.
### Does it work with +-10V?
No.
### GCC complains about missing files.
Use the Makefile. It generates code at compile time.

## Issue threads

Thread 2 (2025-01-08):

Add DMM servo encoder protocol

ShadeTechnik, 2025-01-08:
Obviously not an issue, but I just noticed this project was resurrected and figured I'd mention this.....

DMM sells reasonably priced servo motors. the drives are OK but are somewhat limited in good options when it comes to integrating them with LinuxCNC. I've never had any issues with the motors and I've used a lot of DMM 5000rpm 750w servos....

I have the encoder protocol documentation. They are RS485 encoders with a similar wiring scheme as the Panasonics shown in the stmbl info. Not sure that DMM wants to make the protocol doc public, but they sent it to me without a request for privacy so if any of the main contributors is interested in adding this protocol to stmbl I can provide the documentation directly to them.

freakontrol, 2025-01-08:
Hi, I can add it to the list of things to do, I will need to buy a DMM motor to debug the protocol. You can write me in the chat, you find it in the Readme.

ShadeTechnik, 2025-01-12:
> @ShadeTechnik As I said in the forum, if you send me the documentation, I will look into it

I didn't see your name as a previous contributor to this stmbl project so I figured it best to post it as an issue so the project was aware of it. I've sent freakontrol the document, you can discuss it with him if you want to do the work but since he's the main driver of the new version, I'll let him figure that out.

freakontrol, 2025-02-17:
Hi, the component for decoding DMM encoder is here:

[https://freakontrol.github.io/stmbl/docs/hal_components/dmm/](https://freakontrol.github.io/stmbl/docs/hal_components/dmm/)
and the template is:

[https://freakontrol.github.io/stmbl/docs/hal_templates/encdmm_fb0/](https://freakontrol.github.io/stmbl/docs/hal_templates/encdmm_fb0/)

I close the issue, feel free to reopen if necessary.

Closed 2025-02-17.

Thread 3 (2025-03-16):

Max 4kw setup

Overspeed666, 2025-03-16:
Hi
220vac ac servo drive
IRAM136-3063B Series 30A, 600V
Is it compatible? How to integrate?

freakontrol, 2025-03-24:
Hi, I don't think so, and moreover that bridge is flagged obsolete.

Closed 2025-03-24.

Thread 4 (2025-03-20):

Its suport ABZ encoder amd Step/dir input??

artayasa, 2025-03-20:
Good day mate, is your project suport step/dir input?? Also for 2000ppr abz encoder or 20bit incremental ABZ encoder mate.??

And to make less spent money can i remove some part thats no need it for other than step/dir input?

freakontrol, 2025-03-24:
Hi, the board can read an incremental encoder as I wrote you in the chat.
I don't think that removing few components will make a big difference to the board cost, but you are free to experiment as long you do it safely.
I confirm again that the board reads step/dir inputs

Closed 2025-03-24.

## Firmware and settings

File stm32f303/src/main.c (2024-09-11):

/*
* This file is part of the stmbl project.
*
* Copyright (C) 2013-2017 Rene Hopf <renehopf@mac.com>
* Copyright (C) 2013-2017 Nico Stute <crinq@crinq.de>
*
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
* You should have received a copy of the GNU General Public License
* along with this program.  If not, see <http://www.gnu.org/licenses/>.
*/

#include "main.h"
#include "stm32f3xx_hal.h"
#include "adc.h"
#include "dac.h"
#include "opamp.h"
#include "tim.h"

#include <math.h>
#include "defines.h"
#include "hal.h"
#include "angle.h"

#include "version.h"
#include "common.h"
#include "commands.h"
#include "f3hw.h"

#include "usbd_cdc_if.h"
#ifdef USB_TERM
#include "usb_device.h"
#endif

volatile uint64_t systime = 0;

void SysTick_Handler(void) {
  /* USER CODE BEGIN SysTick_IRQn 0 */
  systime++;
  /* USER CODE END SysTick_IRQn 0 */
  HAL_IncTick();
  HAL_SYSTICK_IRQHandler();
}

uint32_t systick_freq;
CRC_HandleTypeDef hcrc;

uint32_t hal_get_systick_value() {
  return (SysTick->VAL);
}

uint32_t hal_get_systick_reload() {
  return (SysTick->LOAD);
}

uint32_t hal_get_systick_freq() {
  return (systick_freq);
}

void SystemClock_Config(void);
void Error_Handler(void);

void TIM8_UP_IRQHandler() {
  GPIOA->BSRR |= GPIO_PIN_9;
  __HAL_TIM_CLEAR_IT(&htim8, TIM_IT_UPDATE);
  hal_run_rt();
  if(__HAL_TIM_GET_FLAG(&htim8, TIM_IT_UPDATE) == SET) {
    hal_stop();
    hal.hal_state = RT_TOO_LONG;
  }
  GPIOA->BSRR |= GPIO_PIN_9 << 16;
}

void about(char *ptr) {
  printf("######## software info ########\n");
  printf(
      "%s v%i.%i.%i %s\n",
      version_info.product_name,
      version_info.major,
      version_info.minor,
      version_info.patch,
      version_info.git_version);
  printf("Branch %s\n", version_info.git_branch);
  printf("Compiled %s %s ", version_info.build_date, version_info.build_time);
  printf("by %s on %s\n", version_info.build_user, version_info.build_host);
  printf("GCC        %s\n", __VERSION__);
  printf("newlib     %s\n", _NEWLIB_VERSION);
#ifdef __CM4_CMSIS_VERSION
  printf("CMSIS      %i.%i\n", __CM4_CMSIS_VERSION_MAIN, __CM4_CMSIS_VERSION_SUB);
#endif
#ifdef __STM32F4XX_STDPERIPH_VERSION
  printf("StdPeriph  %i.%i.%i\n", __STM32F4XX_STDPERIPH_VERSION_MAIN, __STM32F4XX_STDPERIPH_VERSION_SUB1, __STM32F4XX_STDPERIPH_VERSION_SUB2);
#endif
#ifdef __STM32F3xx_HAL_VERSION
  printf("HAL lib... TODO: print version\n");
#endif
}

COMMAND("about", about, "show system infos");

void bootloader(char *ptr) {
#ifdef USB_DISCONNECT_PIN
  HAL_GPIO_WritePin(USB_DISCONNECT_PORT, USB_DISCONNECT_PIN, GPIO_PIN_SET);
  HAL_Delay(100);
#endif
  RTC->BKP0R = 0xDEADBEEF;
  NVIC_SystemReset();
}

COMMAND("bootloader", bootloader, "enter bootloader");

void reset(char *ptr) {
  HAL_NVIC_SystemReset();
}
COMMAND("reset", reset, "reset STMBL");

int main(void) {
  // Relocate interrupt vectors
  extern void *g_pfnVectors;
  SCB->VTOR = (uint32_t)&g_pfnVectors;

  /* Reset of all peripherals, Initializes the Flash interface and the Systick. */
  HAL_Init();

  /* Configure the system clock */
  SystemClock_Config();
  systick_freq = HAL_RCC_GetHCLKFreq();
  /* Initialize all configured peripherals */
  __HAL_RCC_GPIOA_CLK_ENABLE();
  __HAL_RCC_GPIOB_CLK_ENABLE();
  __HAL_RCC_GPIOC_CLK_ENABLE();
  __HAL_RCC_GPIOF_CLK_ENABLE();

  GPIO_InitTypeDef GPIO_InitStruct;

#ifdef USB_DISCONNECT_PIN
  GPIO_InitStruct.Pin   = USB_DISCONNECT_PIN;
  GPIO_InitStruct.Mode  = GPIO_MODE_OUTPUT_PP;
  GPIO_InitStruct.Pull  = GPIO_NOPULL;
  GPIO_InitStruct.Speed = GPIO_SPEED_FREQ_LOW;
  HAL_GPIO_Init(USB_DISCONNECT_PORT, &GPIO_InitStruct);
  HAL_GPIO_WritePin(USB_DISCONNECT_PORT, USB_DISCONNECT_PIN, GPIO_PIN_RESET);
#endif

  MX_TIM8_Init();
  MX_ADC1_Init();
  MX_ADC2_Init();
  MX_ADC3_Init();
  MX_ADC4_Init();
  MX_DAC_Init();
  //COMP1 in+ pa1(ADC1_IN2)  in- pa4(dac1_ch1) out TIM8 BRK2
  COMP1->CSR = COMP_CSR_COMPxINSEL_2 | COMP1_CSR_COMP1OUTSEL_2 | COMP_CSR_COMPxEN;
  //COMP2 in+ pa7(ADC2_IN4)  in- pa4(dac1_ch1) out TIM8 BRK_ACTH COMP_CSR_COMPxNONINSEL
  COMP2->CSR = COMP_CSR_COMPxINSEL_2 | COMP2_CSR_COMP2OUTSEL_0 | COMP2_CSR_COMP2OUTSEL_1 | COMP_CSR_COMPxEN;
  //COMP4 in+ pb0(ADC3_IN12) in- pa4(dac1_ch1)  out TIM8 BRK
  COMP4->CSR = COMP_CSR_COMPxINSEL_2 | COMP4_CSR_COMP4OUTSEL_0 | COMP4_CSR_COMP4OUTSEL_1 | COMP_CSR_COMPxEN;
  MX_OPAMP1_Init();
  MX_OPAMP2_Init();
  MX_OPAMP3_Init();
  // MX_USART1_UART_Init();

#ifdef USB_TERM
  MX_USB_DEVICE_Init();
#endif

#ifdef USB_CONNECT_PIN
  GPIO_InitStruct.Pin   = USB_CONNECT_PIN;
  GPIO_InitStruct.Mode  = GPIO_MODE_OUTPUT_PP;
  GPIO_InitStruct.Pull  = GPIO_NOPULL;
  GPIO_InitStruct.Speed = GPIO_SPEED_FREQ_LOW;
  HAL_GPIO_Init(USB_CONNECT_PORT, &GPIO_InitStruct);
  HAL_GPIO_WritePin(USB_CONNECT_PORT, USB_CONNECT_PIN, GPIO_PIN_SET);
#endif

  __HAL_RCC_DMA1_CLK_ENABLE();
  __HAL_RCC_DMA2_CLK_ENABLE();
  __HAL_RCC_RTC_ENABLE();

  /* USER CODE BEGIN 2 */
  HAL_ADCEx_Calibration_Start(&hadc1, ADC_SINGLE_ENDED);
  HAL_ADCEx_Calibration_Start(&hadc2, ADC_SINGLE_ENDED);
  HAL_ADCEx_Calibration_Start(&hadc3, ADC_SINGLE_ENDED);
  HAL_ADCEx_Calibration_Start(&hadc4, ADC_SINGLE_ENDED);

  HAL_OPAMP_SelfCalibrate(&hopamp1);
  HAL_OPAMP_SelfCalibrate(&hopamp2);
  HAL_OPAMP_SelfCalibrate(&hopamp3);

  hcrc.Instance                     = CRC;
  hcrc.Init.DefaultPolynomialUse    = DEFAULT_POLYNOMIAL_ENABLE;
  hcrc.Init.DefaultInitValueUse     = DEFAULT_INIT_VALUE_ENABLE;
  hcrc.Init.InputDataInversionMode  = CRC_INPUTDATA_INVERSION_NONE;
  hcrc.Init.OutputDataInversionMode = CRC_OUTPUTDATA_INVERSION_DISABLE;
  hcrc.InputDataFormat              = CRC_INPUTDATA_FORMAT_WORDS;

  __HAL_RCC_CRC_CLK_ENABLE();

  if(HAL_CRC_Init(&hcrc) != HAL_OK) {
    Error_Handler();
  }

  //IO pins
  GPIO_InitStruct.Pin   = GPIO_PIN_9 | GPIO_PIN_10;
  GPIO_InitStruct.Mode  = GPIO_MODE_OUTPUT_PP;
  GPIO_InitStruct.Pull  = GPIO_NOPULL;
  GPIO_InitStruct.Speed = GPIO_SPEED_FREQ_LOW;
  HAL_GPIO_Init(GPIOA, &GPIO_InitStruct);

  if(HAL_OPAMP_Start(&hopamp1) != HAL_OK) {
    Error_Handler();
  }
  if(HAL_OPAMP_Start(&hopamp2) != HAL_OK) {
    Error_Handler();
  }
  if(HAL_OPAMP_Start(&hopamp3) != HAL_OK) {
    Error_Handler();
  }

  htim8.Instance->CCR1 = 0;
  htim8.Instance->CCR2 = 0;
  htim8.Instance->CCR3 = 0;

  HAL_ADC_Start(&hadc1);
  HAL_ADC_Start(&hadc2);
  HAL_ADC_Start(&hadc3);
  HAL_ADC_Start(&hadc4);
  HAL_DAC_Start(&hdac, DAC_CHANNEL_1);
  HAL_DAC_SetValue(&hdac, DAC_CHANNEL_1, DAC_ALIGN_12B_R, 0);
  if(HAL_TIM_Base_Start_IT(&htim8) != HAL_OK) {
    Error_Handler();
  }
#ifndef PWM_INVERT
  TIM8->RCR = 1;  //uptate event foo
#endif
  if(HAL_TIM_PWM_Start(&htim8, TIM_CHANNEL_1) != HAL_OK) {
    Error_Handler();
  }
  if(HAL_TIM_PWM_Start(&htim8, TIM_CHANNEL_2) != HAL_OK) {
    Error_Handler();
  }
  if(HAL_TIM_PWM_Start(&htim8, TIM_CHANNEL_3) != HAL_OK) {
    Error_Handler();
  }
  if(HAL_TIMEx_PWMN_Start(&htim8, TIM_CHANNEL_1) != HAL_OK) {
    Error_Handler();
  }
  if(HAL_TIMEx_PWMN_Start(&htim8, TIM_CHANNEL_2) != HAL_OK) {
    Error_Handler();
  }
  if(HAL_TIMEx_PWMN_Start(&htim8, TIM_CHANNEL_3) != HAL_OK) {
    Error_Handler();
  }

  hal_init(1.0 / 15000.0, 0.0);
  // hal load comps
  hal_parse("debug_level 1");
  hal_parse("load term");
  // load_comp(comp_by_name("sim"));
  hal_parse("load io");
  hal_parse("load ls");
  hal_parse("load dq");
  hal_parse("load idq");
  hal_parse("load svm");
  hal_parse("load hv");
  hal_parse("load curpid");

  hal_parse("ls0.rt_prio = 0.6");
  hal_parse("io0.rt_prio = 1.0");
  hal_parse("dq0.rt_prio = 2.0");
  hal_parse("curpid0.rt_prio = 3.0");
  hal_parse("idq0.rt_prio = 4.0");
  hal_parse("svm0.rt_prio = 5.0");
  hal_parse("hv0.rt_prio = 6.0");

  hal_parse("term0.send_step = 0.0");

  //link LS
  hal_parse("ls0.mot_temp = io0.mot_temp");
  hal_parse("ls0.dc_volt = io0.udc");
  hal_parse("ls0.hv_temp = io0.hv_temp");
  hal_parse("ls0.fault_in = io0.fault");
  hal_parse("io0.led = ls0.fault");
  hal_parse("curpid0.id_cmd = ls0.d_cmd");
  hal_parse("curpid0.iq_cmd = ls0.q_cmd");
  hal_parse("idq0.pos = ls0.pos");
  hal_parse("idq0.mode = ls0.phase_mode");
  hal_parse("dq0.pos = ls0.pos");
  hal_parse("dq0.mode = ls0.phase_mode");
  hal_parse("io0.hv_en = ls0.en");
  hal_parse("io0.dac = ls0.dac");

  //ADC TEST
  hal_parse("hv0.udc = io0.udc");
  hal_parse("dq0.u = io0.iu");
  hal_parse("dq0.v = io0.iv");
  hal_parse("dq0.w = io0.iw");

  hal_parse("svm0.u = idq0.u");
  hal_parse("svm0.v = idq0.v");
  hal_parse("svm0.w = idq0.w");
  hal_parse("hv0.u = svm0.su");
  hal_parse("hv0.v = svm0.sv");
  hal_parse("hv0.w = svm0.sw");
  hal_parse("svm0.udc = io0.udc");
  hal_parse("curpid0.id_fb = dq0.d");
  hal_parse("curpid0.iq_fb = dq0.q");
  hal_parse("ls0.id_fb = dq0.d");
  hal_parse("ls0.iq_fb = dq0.q");
  hal_parse("ls0.ud_fb = curpid0.ud");
  hal_parse("ls0.uq_fb = curpid0.uq");
  hal_parse("ls0.y = dq0.y");
  hal_parse("ls0.u_fb = io0.u");
  hal_parse("ls0.v_fb = io0.v");
  hal_parse("ls0.w_fb = io0.w");
  hal_parse("idq0.d = curpid0.ud");
  hal_parse("idq0.q = curpid0.uq");
  hal_parse("curpid0.r = ls0.r");
  hal_parse("curpid0.ld = ls0.l");
  hal_parse("curpid0.lq = ls0.l");
  hal_parse("curpid0.psi = ls0.psi");
  hal_parse("curpid0.cur_bw = ls0.cur_bw");
  hal_parse("curpid0.ff = ls0.cur_ff");
  hal_parse("curpid0.kind = ls0.cur_ind");
  hal_parse("curpid0.max_cur = ls0.max_cur");
  hal_parse("curpid0.pwm_volt = ls0.pwm_volt");
  hal_parse("curpid0.vel = ls0.vel");
  hal_parse("curpid0.en = ls0.en");
  hal_parse("curpid0.cmd_mode = ls0.cmd_mode");
  hal_parse("hv0.arr = ls0.arr");
  hal_parse("io0.ignore_fault_pin = ls0.ignore_fault_pin");
  // hal_parse("load sensorless");
  // hal_parse("sensorless0.rt_prio = 7");
  // hal_parse("sensorless0.r = ls0.r");
  // hal_parse("sensorless0.l = ls0.l");
  // hal_parse("sensorless0.id = dq0.d");
  // hal_parse("sensorless0.iq = dq0.q");
  // hal_parse("sensorless0.ud = curpid0.ud");
  // hal_parse("sensorless0.uq = curpid0.uq");
  hal_parse("hv0.iu = io0.iu");
  hal_parse("hv0.iv = io0.iv");
  hal_parse("hv0.iw = io0.iw");

  hal_parse("debug_level 0");

  // hal parse config
  // hal_init_nrt();
  // error foo
  hal_start();

  while(1) {
    hal_run_nrt();
    cdc_poll();
    HAL_Delay(1);
  }
}

/** System Clock Configuration
*/
void SystemClock_Config(void) {
  RCC_OscInitTypeDef RCC_OscInitStruct;
  RCC_ClkInitTypeDef RCC_ClkInitStruct;
  RCC_PeriphCLKInitTypeDef PeriphClkInit;

  /**Initializes the CPU, AHB and APB busses clocks 
    */
  RCC_OscInitStruct.OscillatorType = RCC_OSCILLATORTYPE_HSE;
  RCC_OscInitStruct.HSEState       = RCC_HSE_ON;
  RCC_OscInitStruct.HSEPredivValue = RCC_HSE_PREDIV_DIV1;
  RCC_OscInitStruct.HSIState       = RCC_HSI_ON;
  RCC_OscInitStruct.LSIState       = RCC_LSI_ON;
  RCC_OscInitStruct.PLL.PLLState   = RCC_PLL_ON;
  RCC_OscInitStruct.PLL.PLLSource  = RCC_PLLSOURCE_HSE;
  RCC_OscInitStruct.PLL.PLLMUL     = RCC_PLL_MUL9;
  if(HAL_RCC_OscConfig(&RCC_OscInitStruct) != HAL_OK) {
    Error_Handler();
  }

  /**Initializes the CPU, AHB and APB busses clocks 
    */
  RCC_ClkInitStruct.ClockType      = RCC_CLOCKTYPE_HCLK | RCC_CLOCKTYPE_SYSCLK | RCC_CLOCKTYPE_PCLK1 | RCC_CLOCKTYPE_PCLK2;
  RCC_ClkInitStruct.SYSCLKSource   = RCC_SYSCLKSOURCE_PLLCLK;
  RCC_ClkInitStruct.AHBCLKDivider  = RCC_SYSCLK_DIV1;
  RCC_ClkInitStruct.APB1CLKDivider = RCC_HCLK_DIV2;
  RCC_ClkInitStruct.APB2CLKDivider = RCC_HCLK_DIV1;

  if(HAL_RCC_ClockConfig(&RCC_ClkInitStruct, FLASH_LATENCY_2) != HAL_OK) {
    Error_Handler();
  }

  //TODO: usb optional
  PeriphClkInit.PeriphClockSelection = RCC_PERIPHCLK_USB | RCC_PERIPHCLK_USART1 | RCC_PERIPHCLK_USART3 | RCC_PERIPHCLK_TIM8 | RCC_PERIPHCLK_ADC12 | RCC_PERIPHCLK_ADC34 | RCC_PERIPHCLK_RTC;
  PeriphClkInit.Usart1ClockSelection = RCC_USART1CLKSOURCE_PCLK2;
  PeriphClkInit.Usart3ClockSelection = RCC_USART3CLKSOURCE_SYSCLK;
  PeriphClkInit.Adc12ClockSelection  = RCC_ADC12PLLCLK_DIV1;
  PeriphClkInit.Adc34ClockSelection  = RCC_ADC34PLLCLK_DIV1;
  PeriphClkInit.USBClockSelection    = RCC_USBCLKSOURCE_PLL_DIV1_5;
  PeriphClkInit.Tim8ClockSelection   = RCC_TIM8CLK_PLLCLK;
  PeriphClkInit.RTCClockSelection    = RCC_RTCCLKSOURCE_LSI;
  if(HAL_RCCEx_PeriphCLKConfig(&PeriphClkInit) != HAL_OK) {
    Error_Handler();
  }

  /**Configure the Systick interrupt time 
    */
  HAL_SYSTICK_Config(HAL_RCC_GetHCLKFreq() / 1000);

  /**Configure the Systick 
    */
  HAL_SYSTICK_CLKSourceConfig(SYSTICK_CLKSOURCE_HCLK);

  /* SysTick_IRQn interrupt configuration */
  HAL_NVIC_SetPriority(SysTick_IRQn, 0, 0);
}

/**
  * @brief  This function is executed in case of error occurrence.
  * @param  None
  * @retval None
  */
void Error_Handler(void) {
  /* User can add his own implementation to report the HAL error return state */
  while(1) {
    HAL_GPIO_WritePin(GPIOA, GPIO_PIN_8, GPIO_PIN_SET);
  }
}

#ifdef USE_FULL_ASSERT

/**
   * @brief Reports the name of the source file and the source line number
   * where the assert_param error has occurred.
   * @param file: pointer to the source file name
   * @param line: assert_param error line source number
   * @retval None
   */
void assert_failed(uint8_t *file, uint32_t line) {
  /* USER CODE BEGIN 6 */
  /* User can add his own implementation to report the file name and line number,
    ex: printf("Wrong parameters value: file %s on line %d\r\n", file, line) */
  /* USER CODE END 6 */
}

#endif

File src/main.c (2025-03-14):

/*
* This file is part of the stmbl project.
*
* Copyright (C) 2013-2015 Rene Hopf <renehopf@mac.com>
* Copyright (C) 2013-2015 Nico Stute <crinq@crinq.de>
*
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
* You should have received a copy of the GNU General Public License
* along with this program.  If not, see <http://www.gnu.org/licenses/>.
*/

//#include "stm32f4xx_conf.h"
#include "hal.h"
#include "setup.h"
#include "defines.h"
#include <string.h>
#include <stdio.h>
#include <stdlib.h>
#include "main.h"
#include "commands.h"

extern RCC_ClocksTypeDef RCC_Clocks;

uint32_t hal_get_systick_value() {
  return (SysTick->VAL);
}

uint32_t hal_get_systick_reload() {
  return (SysTick->LOAD);
}

uint32_t hal_get_systick_freq() {
  return (RCC_Clocks.HCLK_Frequency);
}

volatile uint64_t systime = 0;

void SysTick_Handler(void) {
  systime++;
}

//20kHz
void TIM_SLAVE_HANDLER(void) {
  TIM_ClearITPendingBit(TIM_SLAVE, TIM_IT_Update);
  hal_run_frt();
  if(TIM_GetITStatus(TIM_SLAVE, TIM_IT_Update) == SET) {
    hal_stop();
    hal.hal_state = FRT_TOO_LONG;
  }
}

//5 kHz interrupt for hal. at this point all ADCs have been sampled,
//see setup_res() in setup.c if you are interested in the magic behind this.
void DMA2_Stream0_IRQHandler(void) {
  DMA_ClearITPendingBit(DMA2_Stream0, DMA_IT_TCIF0);
  hal_run_rt();
  if(DMA_GetITStatus(DMA2_Stream0, DMA_IT_TCIF0) == SET) {
    hal_stop();
    hal.hal_state = RT_TOO_LONG;
  }
}

void bootloader(char *ptr) {
  hal_stop();

  NVIC_DisableIRQ(TIM_SLAVE_IRQ);
  NVIC_DisableIRQ(DMA2_Stream0_IRQn);
  NVIC_DisableIRQ(SysTick_IRQn);

  void (*SysMemBootJump)(void);
  volatile uint32_t addr = 0x1FFF0000;

  RCC_DeInit();
  SysTick->CTRL = 0;
  SysTick->LOAD = 0;
  SysTick->VAL  = 0;

  RCC->AHB1RSTR = 0x22E017FF;
  RCC->AHB1RSTR = 0;
  RCC->AHB2RSTR = 0xF1;
  RCC->AHB2RSTR = 0;
  RCC->AHB3RSTR = 0x1;
  RCC->AHB3RSTR = 0;
  RCC->APB1RSTR = 0xF6FEC9FF;
  RCC->APB1RSTR = 0;
  RCC->APB2RSTR = 0x4777933;
  RCC->APB2RSTR = 0;

  SYSCFG->MEMRMP = 0x01;
  SysMemBootJump = (void (*)(void))(*((uint32_t *)(addr + 4)));
  __set_MSP(*(uint32_t *)addr);
  SysMemBootJump();
}
COMMAND("bootloader", bootloader, "enter bootloader");

void nv_reset(char *ptr) {
  NVIC_SystemReset();
}
COMMAND("reset", nv_reset, "reset STMBL");

void about(char *ptr) {
  printf("######## software info ########\n");
  printf(
      "%s v%i.%i.%i %s\n",
      version_info.product_name,
      version_info.major,
      version_info.minor,
      version_info.patch,
      version_info.git_version);
  printf("Branch %s\n", version_info.git_branch);
  printf("Compiled %s %s ", version_info.build_date, version_info.build_time);
  printf("by %s on %s\n", version_info.build_user, version_info.build_host);
  printf("GCC        %s\n", __VERSION__);
  printf("newlib     %s\n", _NEWLIB_VERSION);
#ifdef __CM4_CMSIS_VERSION
  printf("CMSIS      %i.%i\n", __CM4_CMSIS_VERSION_MAIN, __CM4_CMSIS_VERSION_SUB);
#endif
#ifdef __STM32F4XX_STDPERIPH_VERSION
  printf("StdPeriph  %i.%i.%i\n", __STM32F4XX_STDPERIPH_VERSION_MAIN, __STM32F4XX_STDPERIPH_VERSION_SUB1, __STM32F4XX_STDPERIPH_VERSION_SUB2);
#endif
#ifdef __STM32F3xx_HAL_VERSION
  printf("HAL lib... TODO: print version\n");
#endif
  printf("CPU ID     %lx %lx %lx\n",U_ID[0], U_ID[1], U_ID[2]);
  printf("size: %lu crc:%lx\n", version_info.image_size, version_info.image_crc);
  volatile const version_info_t *bt_version_info = (void *)0x08000188;
  printf("######## Bootloader info ########\n");
  printf(
      "%s v%i.%i.%i %s\n",
      bt_version_info->product_name,
      bt_version_info->major,
      bt_version_info->minor,
      bt_version_info->patch,
      bt_version_info->git_version);
  extern uint8_t _binary_obj_hvf3_hvf3_bin_start;
  extern uint8_t _binary_obj_hvf3_hvf3_bin_size;
  extern uint8_t _binary_obj_hvf3_hvf3_bin_end;
  volatile const version_info_t *hv_version_info = (void *)(&_binary_obj_hvf3_hvf3_bin_start + 0x188);
  printf("######## HV info ########\n");
  printf(
      "%s v%i.%i.%i %s\n",
      hv_version_info->product_name,
      hv_version_info->major,
      hv_version_info->minor,
      hv_version_info->patch,
      hv_version_info->git_version);
  // printf("Branch %s\n",bt_version_info->git_branch);
  // printf("Compiled %s %s ",bt_version_info->build_date, bt_version_info->build_time);
  // printf("by %s on %s\n",bt_version_info->build_user, bt_version_info->build_host);
  //

  printf("hv start:%p ,size:%p ,end%p \n", &_binary_obj_hvf3_hvf3_bin_start, &_binary_obj_hvf3_hvf3_bin_size, &_binary_obj_hvf3_hvf3_bin_end);
}

COMMAND("about", about, "show system infos");


void sleep(char *ptr) {
  float foo = 0;
  sscanf(ptr, " %f", &foo);
  printf("sleeping for %fs\n", foo);
  Wait((uint32_t)(foo * 1000));
  printf("wakeup\n");
}

COMMAND("sleep", sleep, "sleep [s]");

int main(void) {
  // Relocate interrupt vectors
  extern void *g_pfnVectors;
  SCB->VTOR = (uint32_t)&g_pfnVectors;

  setup();
  hal_init(0.0002, 0.00005);
  // hal load comps
  load_comp(comp_by_name("term"));
  hal_parse("flashloadconf");
  hal_parse("loadconf");
  hal_parse("relink");
  hal_parse("start");

  TIM_Cmd(TIM_MASTER, ENABLE);
  TIM_ITConfig(TIM_SLAVE, TIM_IT_Update, ENABLE);

  while(1)  //run non realtime stuff
  {
    hal_run_nrt();
    //cdc_poll();
    Wait(1);
  }
}

void Wait(uint32_t ms) {
  uint64_t t = systime + ms;
  while(t >= systime) {
  }
}

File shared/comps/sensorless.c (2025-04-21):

#include "sensorless_comp.h"
/*
* This file is part of the stmbl project.
*
* Copyright (C) 2013-2016 Rene Hopf <renehopf@mac.com>
* Copyright (C) 2013-2016 Nico Stute <crinq@crinq.de>
* Copyright (C) 2025-2026 Thomas Deponte <deponte.thomas@gmail.com>
*
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
* You should have received a copy of the GNU General Public License
* along with this program.  If not, see <http://www.gnu.org/licenses/>.
*/


/**
* ## Brief
* The `sensorless` component is responsible for estimating the motor's velocity and position in real-time using electrical measurements. It applies low-pass filtering, back EMF calculation, velocity compensation, and position integration to achieve this.  
*
* ## Description  
* 
* 1. **Input Reading and Initialization**:
*    - `l` and `r` are the inductance and resistance of the motor, respectively. They are ensured to be positive.
*    - The voltage measurements `ud` and `uq` are updated using a delay line (`ud2`, `uq2`, `ud1`, `uq1`, `ud`, `uq`).
*    - The current measurements `id` and `iq` are read from the input pins.
* 
* 2. **Gain Clamping**:
*    - The gains `kb`, `ki`, and `kl` are clamped to ensure they stay within valid ranges.
* 
* 3. **Low-Pass Filtering of Current Changes**:
*    - The changes in currents `delta_id` and `delta_iq` are calculated using a low-pass filter. This helps to smooth out noise in the current measurements.
*    - The previous current values `old_id` and `old_iq` are updated to the current measurements.
* 
* 4. **Back EMF Calculation**:
*    - The back EMF (`ed` and `eq`) is estimated using the motor's electrical equations. The back EMF is the voltage generated by the motor due to its rotation.
*   - The equations used are:
*     ```c
*     ed = ud - r * id - PIN(delta_id) * l / period + vel * l * iq * kb;
*     eq = uq - r * iq - PIN(delta_iq) * l / period - vel * l * id * kb;
*     ```
*
* 5. **Velocity Compensation**:
*    - The estimated velocity `vel` is adjusted to compensate for the back EMF. The goal is to make the d-axis back EMF (`ed`) approach zero, which helps in stabilizing the control.
*    - The compensation is done using the following equation:
*      ```c
*      vel -= SIGN2(eq, 1.0) * ed * ki * period;
*      ```
*  
* 6. **Startup Boost**:
*    - If the absolute value of the estimated velocity is below a minimum threshold (`min_vel`), a boost is added to help the motor start up more reliably.
*    - The boost is applied using the following equation:
*      ```c
*      vel += SIGN2(id * iq, 0.1) * PIN(vel_boost);
*      ```
*  
* 7. **Velocity Limiting**:
*    - The estimated velocity is limited to ensure it does not exceed the maximum allowed value (`max_vel`).
*  
* 8. **Position Update**:
*    - The estimated position `pos` is updated by integrating the estimated velocity over time.
*    - The position is wrapped using the `mod` function to ensure it stays within a valid range (e.g., 0 to 2π for angular position).
*  
* 9. **Output Updates**:
*    - The estimated back EMF (`ed` and `eq`), velocity (`vel`), and position (`pos`) are updated on the output pins.  
*/

#include "commands.h"
#include "hal.h"
#include "math.h"
#include "defines.h"
#include "angle.h"


HAL_COMP(sensorless);

// Input pins
HAL_PIN(r);          // *parameter*, Resistance of the motor (R)
HAL_PIN(l);          // *parameter*, Inductance of the motor (L)

// Gain parameters for the control algorithm
HAL_PIN(ki);         // *parameter*, Integral gain for velocity compensation
HAL_PIN(kb);         // *parameter*, Back EMF gain
HAL_PIN(kl);         // *parameter*, Low-pass filter gain for current changes

// Velocity control parameters
HAL_PIN(min_vel);    // *parameter*, Minimum velocity threshold for startup boost
HAL_PIN(vel_boost);  // *parameter*, Velocity boost factor for startup
HAL_PIN(max_vel);    // *parameter*, Maximum allowed velocity

// Current and voltage measurements in the d-q reference frame
HAL_PIN(id);         // *input*, D-axis current
HAL_PIN(iq);         // *input*, Q-axis current
HAL_PIN(ud);         // *input*, D-axis voltage (current measurement)
HAL_PIN(uq);         // *input*, Q-axis voltage (current measurement)
HAL_PIN(ud1);        // *internal*, Delayed D-axis voltage (one sample delay)
HAL_PIN(uq1);        // *internal*, Delayed Q-axis voltage (one sample delay)
HAL_PIN(ud2);        // *internal*, Delayed D-axis voltage (two sample delays)
HAL_PIN(uq2);        // *internal*, Delayed Q-axis voltage (two sample delays)

// Output pins
HAL_PIN(vel);        // *output*, Estimated velocity of the motor
HAL_PIN(pos);        // *output*, Estimated position of the motor

// Estimated back EMF in the d-q reference frame
HAL_PIN(ed);         // *output*, D-axis back EMF
HAL_PIN(eq);         // *output*, Q-axis back EMF

// Previous current values for low-pass filtering
HAL_PIN(old_id);     // Previous D-axis current
HAL_PIN(old_iq);     // Previous Q-axis current

// Changes in current for back EMF calculation
HAL_PIN(delta_id);   // *output*, Change in D-axis current
HAL_PIN(delta_iq);   // *output*, Change in Q-axis current

static void nrt_init(void *ctx_ptr, hal_pin_inst_t *pin_ptr) {
  // struct sensorless_ctx_t *ctx      = (struct sensorless_ctx_t *)ctx_ptr;
  struct sensorless_pin_ctx_t *pins = (struct sensorless_pin_ctx_t *)pin_ptr;
  PIN(ki)                           = 1500.0;
  PIN(kb)                           = 1;
  PIN(kl)                           = 0.75;
  PIN(min_vel)                      = 3.0 * 2.0 * M_PI;
  PIN(vel_boost)                    = 0.2;
  PIN(max_vel)                      = 500.0 * 2.0 * M_PI * 1.1;
}

static void rt_func(float period, void *ctx_ptr, hal_pin_inst_t *pin_ptr) {
  // struct sensorless_ctx_t *ctx      = (struct sensorless_ctx_t *)ctx_ptr;
  struct sensorless_pin_ctx_t *pins = (struct sensorless_pin_ctx_t *)pin_ptr;

  float l = MAX(PIN(l), 0.00001);
  float r = MAX(PIN(r), 0.01);

  float ud = PIN(ud2);
  float uq = PIN(uq2);
  PIN(ud2) = PIN(ud1);
  PIN(uq2) = PIN(uq1);
  PIN(ud1) = PIN(ud);
  PIN(uq1) = PIN(uq);

  float id = PIN(id);
  float iq = PIN(iq);

  float kb = CLAMP(PIN(kb), 0, 1);
  float ki = CLAMP(PIN(ki), 0, 1.0 / period);
  float kl = CLAMP(PIN(kl), 0, 1);

  float vel = PIN(vel);
  float pos = PIN(pos);

  // lowpass current change
  PIN(delta_id) = PIN(delta_id) * kl + (id - PIN(old_id)) * (1 - kl);
  PIN(delta_iq) = PIN(delta_iq) * kl + (iq - PIN(old_iq)) * (1 - kl);

  PIN(old_id) = id;
  PIN(old_iq) = iq;

  // calc bemf
  float ed = ud - r * id - PIN(delta_id) * l / period + vel * l * iq * kb;
  float eq = uq - r * iq - PIN(delta_iq) * l / period - vel * l * id * kb;

  // velocity compensation, bemf_d -> 0
  vel -= SIGN2(eq, 1.0) * ed * ki * period;

  // startup boost
  if(ABS(vel) < PIN(min_vel)) {
    vel += SIGN2(id * iq, 0.1) * PIN(vel_boost);
  }

  vel = LIMIT(vel, PIN(max_vel));

  pos += vel * period;

  PIN(ed) = ed;
  PIN(eq) = eq;

  PIN(vel) = vel;
  PIN(pos) = mod(pos);
}
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

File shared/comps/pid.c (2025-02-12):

/**
 * PID (Proportional-Integral-Derivative) Controller Component
 *
 * This component implements a PID controller, which is used to minimize the error between a desired setpoint and the actual process variable.
 * The PID algorithm calculates an output value based on the proportional, integral, and derivative terms of the error.
 * It is widely used in control systems for applications such as motor speed control, temperature regulation, and more.
 */

#include "pid_comp.h"
/*
* This file is part of the stmbl project.
*
* Copyright (C) 2013-2016 Rene Hopf <renehopf@mac.com>
* Copyright (C) 2013-2016 Nico Stute <crinq@crinq.de>
*
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
* You should have received a copy of the GNU General Public License
* along with this program.  If not, see <http://www.gnu.org/licenses/>.
*/

#include "commands.h"
#include "hal.h"
#include "math.h"
#include "defines.h"
#include "angle.h"

HAL_COMP(pid);

HAL_PIN(pos_ext_cmd);  // cmd in (rad)
HAL_PIN(pos_fb);       // feedback in (rad)
HAL_PIN(pos_error);    // error out (rad)

HAL_PIN(vel_ext_cmd);  // cmd in (rad/s)
HAL_PIN(vel_fb);       // feedback in (rad/s)
HAL_PIN(vel_cmd);      // cmd out (rad/s)
HAL_PIN(vel_error);    // error out (rad/s)

HAL_PIN(acc_ext_cmd);  // cmd in (rad/s^2)
HAL_PIN(acc_cmd);      // cmd out (rad/s^2)
HAL_PIN(acc_cmd_lp);   // cmd out (rad/s^2)
HAL_PIN(acc_cmd_hp);   // cmd out (rad/s^2)

HAL_PIN(torque_ext_cmd);  // cmd in (Nm)
HAL_PIN(fb_torque_cmd);   // feedback cmd out (Nm)
HAL_PIN(ff_torque_cmd);   // feedforward cmd out (Nm)
HAL_PIN(torque_cmd);      // cmd out (Nm)
HAL_PIN(torque_sum);

HAL_PIN(en);
HAL_PIN(pos_en);
HAL_PIN(vel_en);

HAL_PIN(pos_bw);  // (1/s)

HAL_PIN(vel_bw);  // (1/s)
HAL_PIN(vel_d);
HAL_PIN(vel_g);
HAL_PIN(torque_g);

HAL_PIN(scale);

HAL_PIN(j_lpf);

HAL_PIN(acc_g);

HAL_PIN(j_mot);  // motor inertia (kgm^2)
HAL_PIN(f);      // (Nm)
HAL_PIN(d);      // (Nm/rad/s)
HAL_PIN(j_sys);  // system inertia(kgm^2)
HAL_PIN(o);      // (Nm)

// user limits
HAL_PIN(max_vel);         // (rad/s)
HAL_PIN(neg_min_vel);     // (rad/s)
HAL_PIN(max_acc);         // (rad/s^2)
HAL_PIN(max_torque);      // (Nm)
HAL_PIN(neg_min_torque);  // (Nm)

HAL_PIN(vel_sat);
HAL_PIN(torque_sat);
HAL_PIN(sat);  // (s)

static void nrt_init(void *ctx_ptr, hal_pin_inst_t *pin_ptr) {
  //struct pid_ctx_t *ctx      = (struct pid_ctx_t *)ctx_ptr;
  struct pid_pin_ctx_t *pins = (struct pid_pin_ctx_t *)pin_ptr;

  PIN(pos_en)   = 1.0;
  PIN(vel_en)   = 1.0;
  PIN(pos_bw)   = 100.0;   // (1/s)
  PIN(vel_bw)   = 2000.0;  // (1/s)
  PIN(vel_d)    = 2.0;
  PIN(vel_g)    = 0.1;
  PIN(torque_g) = 1.0;

  PIN(scale) = 1.0;
}

static void rt_func(float period, void *ctx_ptr, hal_pin_inst_t *pin_ptr) {
  //struct pid_ctx_t *ctx      = (struct pid_ctx_t *)ctx_ptr;
  struct pid_pin_ctx_t *pins = (struct pid_pin_ctx_t *)pin_ptr;

  float lpf = LP_HZ(MAX(PIN(j_lpf), 0.0));

  if(PIN(en) > 0.0) {
    if(PIN(pos_en) > 0.0) {
      // pos -> vel
      PIN(pos_error) = minus(PIN(pos_ext_cmd), PIN(pos_fb));
      PIN(vel_cmd)   = PIN(pos_error) * PIN(pos_bw) * PIN(scale);                                     // p
      if(ABS(SAT2(PIN(vel_cmd), -PIN(neg_min_vel) * PIN(vel_g), PIN(max_vel) * PIN(vel_g))) > 0.0) {  // saturation
        PIN(vel_sat) += period;
      } else {
        PIN(vel_sat) = MAX(PIN(vel_sat) - period, 0.0);
      }
      PIN(vel_cmd) = CLAMP(PIN(vel_cmd), -PIN(neg_min_vel) * PIN(vel_g), PIN(max_vel) * PIN(vel_g));  // p clamping
      PIN(vel_cmd) += PIN(vel_ext_cmd);                                                               // ff
      PIN(vel_cmd) = CLAMP(PIN(vel_cmd), -PIN(neg_min_vel), PIN(max_vel));                            // clamping
    } else {
      PIN(pos_error) = 0.0;
      PIN(vel_cmd)   = 0.0;
      PIN(vel_sat)   = 0.0;
    }

    if(PIN(vel_en) > 0.0) {
      // vel -> acc
      PIN(vel_error) = PIN(vel_cmd) - PIN(vel_fb);
      PIN(acc_cmd)   = PIN(vel_error) * PIN(vel_bw) * PIN(scale);  // p
      PIN(acc_cmd)   = LIMIT(PIN(acc_cmd), PIN(max_acc));          // clamping

      PIN(torque_sum) += PIN(vel_error) * PIN(vel_bw) * PIN(vel_bw) * PIN(scale) * PIN(scale) / MAX(PIN(vel_d), 0.1) * (PIN(j_mot) + PIN(j_sys)) * period;  // i
    } else {
      PIN(vel_error)  = 0.0;
      PIN(acc_cmd)    = 0.0;
      PIN(torque_sum) = 0.0;
    }


    // acc -> torque
    PIN(acc_cmd_lp) = PIN(acc_cmd) * lpf + PIN(acc_cmd_lp) * (1.0 - lpf);
    PIN(acc_cmd_hp) = PIN(acc_cmd) - PIN(acc_cmd_lp);

    PIN(fb_torque_cmd) = PIN(acc_cmd_hp) * PIN(j_mot) + PIN(acc_cmd_lp) * (PIN(j_mot) + PIN(j_sys));
    PIN(fb_torque_cmd) = CLAMP(PIN(fb_torque_cmd), -PIN(neg_min_torque) * PIN(torque_g), PIN(max_torque) * PIN(torque_g));                                         // clamping
    PIN(torque_sum)    = CLAMP(PIN(torque_sum), -PIN(neg_min_torque) * PIN(torque_g) - PIN(fb_torque_cmd), PIN(max_torque) * PIN(torque_g) - PIN(fb_torque_cmd));  // dynamic integral clamping
    PIN(fb_torque_cmd) += PIN(torque_sum);

    if(ABS(SAT2(PIN(fb_torque_cmd), -PIN(neg_min_torque) * PIN(torque_g) * 0.99, PIN(max_torque) * PIN(torque_g) * 0.99)) > 0.0) {  // saturation
      PIN(torque_sat) += period;
    } else {
      PIN(torque_sat) = MAX(PIN(torque_sat) - period, 0.0);
    }

    PIN(ff_torque_cmd) = PIN(acc_ext_cmd) * (PIN(j_mot) + PIN(j_sys));
    PIN(ff_torque_cmd) += PIN(d) * PIN(vel_cmd);
    PIN(ff_torque_cmd) += PIN(f) * SIGN2(PIN(vel_cmd), PIN(max_vel) * 0.001);
    PIN(ff_torque_cmd) += PIN(o);

    PIN(torque_cmd) = CLAMP(PIN(torque_ext_cmd) + PIN(ff_torque_cmd) + PIN(fb_torque_cmd), -PIN(neg_min_torque), PIN(max_torque));

    // sat
    PIN(sat) = MAX(PIN(vel_sat), PIN(torque_sat));
  } else {
    PIN(pos_error)     = 0.0;
    PIN(vel_cmd)       = 0.0;
    PIN(vel_error)     = 0.0;
    PIN(acc_cmd)       = 0.0;
    PIN(torque_cmd)    = 0.0;
    PIN(acc_cmd_lp)    = 0.0;
    PIN(acc_cmd_hp)    = 0.0;
    PIN(vel_sat)       = 0.0;
    PIN(torque_sat)    = 0.0;
    PIN(sat)           = 0.0;
    PIN(torque_sum)    = 0.0;
    PIN(fb_torque_cmd) = 0.0;
    PIN(ff_torque_cmd) = 0.0;
    PIN(torque_cmd)    = 0.0;
  }
}

hal_comp_t pid_comp_struct = {
    .name      = "pid",
    .nrt       = 0,
    .rt        = rt_func,
    .frt       = 0,
    .nrt_init  = nrt_init,
    .rt_start  = 0,
    .frt_start = 0,
    .rt_stop   = 0,
    .frt_stop  = 0,
    .ctx_size  = 0,
    .pin_count = sizeof(struct pid_pin_ctx_t) / sizeof(struct hal_pin_inst_t),
};

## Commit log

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2025-04-23 Correct the acim pin descriptions
    [acim_ttc.c]
2026-10-23 build: the F3 fits with gcc 12, version info links with binutils 2.42
    With gcc 12.2 and its newlib (Debian bookworm) the F3 image overflowed
    flash by up to 3 KB before the LL port and CCM by 16-32 B after it.
    - F3: the ST drivers, setup (adc, dac, opamp, tim, msp, periph),
    terminal, commands, ringbuf, hal_tbl, version, USB CDC glue and hal.o
    are built with -Os. hal_run_rt in CCM is a loop of rt calls (124 -> 110
    instructions). The rt components (ls, io, curpid, idq, hv, dq, svm, emf,
    the observers), angle, main (the rt interrupt) and the link CRC keep
    $(OPT).
    - F3: newlib's dtoa and mprec call assert(), which links fiprintf and a
    second printf core. A local __assert_func resets i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
2026-10-23 f3 hv: 2 us dead time, min_on/min_off correction, dead time compensation
    - PWM dead time 2.0 us as the IPM datasheets ask (PWM_DEADTIME 196, a
    BDTR.DTG code: 288 ticks).
    - min_on and min_off are both checked against the uncorrected compares,
    so one cannot undo the other. A phase spread wider than the room they
    leave is scaled down around its center, and a per phase floor catches
    what a common mode shift cannot fix. Compare units come from the timer
    clock (144 MHz, center aligned). min_on and min_off default to 3 us.
    - Dead time compensation: while a phase current keeps its sign the bridge
    loses the dead time's share of the period times the link voltage.
    hv0.drop_k scales that i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
2026-10-23 conf templates: fix dead links in the id, pid, mpid, uf and fanuc_io templates
    id_pmsm fed fault0.sat a zero instead of the nonexistent sat_error, so the
    saturation fault no longer stays armed through identification. id_dc
    named idq0 pins that iddc does not have. id_mot fed the offset estimate to
    a renamed pid pin, so fb_torque kept its dc part and conf0.o integrated
    open loop. id_mot also runs the bare motor with pid0.j_sys 0 and gives the
    offset loop li 0.005 (25 s).
    Motor templates: fault0.min_dc_volt follows conf0.low_dc_volt (pid, mpid,
    uf); a board whose saved conf never set low_dc_volt reads 0 there. The
    vel_error links go (fault has no velocity error fault). uf and mpid link
    hv0.cur_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
2026-10-23 acim_ttc: slip cap in field weakening, slip compensation, power limit
    - In slip control, holding t_boost at reduced flux needs slip ~ 1/scale^2;
    past scale = t_boost/s_boost the slip cap binds first, so t_max is
    clamped to what the cap can orient.
    - slip_comp: one linear term in the depth of field weakening for the
    Rr/Lr drift there, inert at and below base speed.
    - p_max: constant power limit, the middle region of the Fanuc slip law
    (EP0078698 eq. 17a).
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2026-10-23 f3: bridge off when the rt stops, W comparator on BRK2, IWDG, V/W overcurrent
    - iabs takes ABS() of all three phases, so negative V and W currents
    reach the software overcurrent checks.
    - TIM8 keeps the last compares when the rt stops; the tick clears MOE and
    the driver enable when it finds the rt stopped.
    - COMP1, phase W's overcurrent comparator, trips TIM8 through BRK2.
    - Independent watchdog at 5 ms from the LSI (HAL_WATCHDOG, f3 only). Only
    the rt kicks, at the end of a completed run, and only while the nrt has
    come round within the last second, so a stopped rt, a hang with irqs
    off or an nrt stuck for 1 s all end in a reset; after the reset HV_EN's
    pull-up holds the gates o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
2026-10-23 f3 hv: dead time compensation curve hv0.drop_knee
    drop_knee > 0 scales the compensation by k(i) = 1 - 1/(1 + |i|/knee)^2 of
    each commanded phase current instead of the latched sign. The latch needs
    drop_band of current to flip, so an unloaded axis sat with a fixed voltage
    vector; the curve cannot stick and falls away like the real loss. On an alpha 3 axis the
    once per turn ripple went 1.0 -> 0.018 A. drop_knee is a config word; 0
    keeps the latch.
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2026-10-23 fault, ipm: short brake, regenerative stop, IPM junction temperature model
    - fault0.sbrake_en: when the drive stops from a powered state for a
    reason that leaves the bridge healthy, fault0 asks for sbrake_time (1 s)
    of braking through a packet flag. The f3 turns all three low sides on
    and chops the current at io0.sbrake_cur (default max_cur, at most
    0.8 x oc_lim). It refuses after any trip since the last enable and stops
    on a trip while braking. With sbrake_arm the f3 also brakes on its own
    when the f4 goes silent while the motor was driven.
    - fault0.rstop_en: on a stop that leaves the feedback, the f3 link and
    the link voltage good, pid0.stop commands zero speed for up to
    rs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
2026-10-23 f3 adc: dual simultaneous mode, PGA sampled 61.5 cycles, rebuild the unsampled phase
    - ADC1/2 and ADC3/4 run regular simultaneous (DUAL 00110, MDMA 10); DMA,
    DUAL/MDMA and DMACFG are all set before the ADCs are enabled
    (RM0316 15.5.4, 15.6.3). Slaves are enabled first.
    - The PGA outputs are sampled for 61.5 cycles (DS9118 table 77 asks for
    at least 400 ns), three current ranks plus the voltage. ADC4 follows
    rank for rank: hv_temp, hv_temp, mot_temp, udc; hv_temp is taken from
    rank 2, after a same-channel sample.
    - A phase near full duty has its low side on for too short a time to be
    sampled; io.c checks each phase's low-side pulse against the sample
    window and the dead time and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
2026-10-23 f3 shutdown: CSS, ARR preload, debug freeze, break interrupt, conf_ok gate
    - Clock security system on (RM0316 20.3.16); the CSS NMI clears CSSC,
    turns the bridge off and stops the hal.
    - TIM8 ARR preloaded, so a phase lock trim cannot skip an overflow.
    - DBG_TIM8_STOP: a breakpoint turns the outputs off.
    - Fault handlers turn the bridge off, record the fault and spin until the
    watchdog; SYSCFG LOCKUP_LOCK routes a core lockup to TIM8's break.
    - TIM8 LOCK level 1 after the break setup.
    - Software trips clear MOE in the same tick, as the comparators do in
    hardware. TIM8_BRK_IRQHandler (priority 0, above the rt) raises HV_EN
    within about a microsecond of a comparator break, so the IPM t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
2026-10-23 f4: DMA re-arm per RM0090, ADC overrun stop, enc_fb, io4, EnDat fixes
    - dma_stream_stop() (inc/dma_util.h) waits for EN = 0 and clears all five
    stream flags before a re-arm (RM0090 10.3.17), in hv, encf, encs,
    yaskawa, sserial, siserial, usart, smartabs, encm, dmm and
    smart_torque. The HV RX stream gets NDTR set before each re-arm.
    - An ADC overrun stops the hal with MISC_ERROR (RM0090 13.8.1); the rt
    would otherwise stop silently.
    - enc_fb: IC1F = IC2F = 0011 (~95 ns) set in CCMR1 after the encoder
    config. DMA2_Stream0_IRQHandler latches TIMx->CNT and the A/B port IDR
    first thing, about 4 us after the last sample; enc_fb uses those, so
    the quadrant check matches the ADC group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
2026-10-23 conf templates: adc0 only where read, reslimit0 after rev0, acim hv0.vel
    - adc0 is scheduled only in res_fb0, enc_fb0, uvw_fb0, uvw_fb1 and wobl;
    it took 45.7 us of the 200 us rt on a Fanuc encoder axis.
    - pid template: reslimit0 runs after rev0, so pos_ext_cmd is from the
    same tick as the velocity and acceleration feedforward. Alpha 3 axis pos_error rms
    at 100-300 rad/s: 1.9-5.7 -> 0.7-0.9 mrad.
    - acim template: hv0.vel from acim_ttc0.vel_e, the synchronous speed with
    slip, for the f3's extrapolation and decoupling.
2026-10-23 f3 io, ipm_im06b50gc1: held IPM temperature decays, Rth from the SOA chart
    - While held, hv_temp decays toward the coolest live reading since power
    up with a 90 s time constant, so a held overtemperature can clear
    without a power cycle; the first live reading after a hold is taken as
    it is. Short braking keeps HV_EN low, so hv_temp is read live 5 ms
    after braking starts.
    - r2temp shows 0 only below 500 ohm and computes ln in float (ln_f, under
    0.0001 K from the double result): 880 B less flash.
    - ipm_im06b50gc1: Rth x2.84, fitted to the datasheet's SOA chart (Fig. 12)
    extended to a 30 C water cooled case.
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2026-10-23 iit: double state, so a minutes-long time constant still integrates
    At a motor-length time constant a float e is so large that one period's
    increment rounds away, and the estimate stalls short of its final value.
2026-10-23 angle, acim_flux, acim_foc, acim_fw: shared commutation angle and rotor flux FOC
    angle owns hv0.pos and hv0.vel for every motor type. src 0 passes the
    feedback through, and pid.txt and pmsm.txt route it, so PMSM axes send the
    same values as before. src 1 integrates rotor speed plus slip (induction
    motor on an encoder), src 2 takes an observer, src 3 an open loop
    frequency; vel is always synchronous electrical speed.
    acim_flux models i_mr with tr, gives slip = iq/(tr*i_mr) and psi =
    lmr*i_mr for hv0.psi, which turns curpid's decoupling into the induction
    motor's stator flux with conf0.l = sigma*Ls. acim_foc ramps id from 0 at
    every enable, holds torque until the flux is up, and limits q so d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
2026-10-23 id_pmsm, id_tune: r, l, psi and offset tests; adv and drop_k
    id_pmsm:
    - r: d dwells at four angles and seven currents, fitted as
    ud = r id + V0 dproj(id, th, knee), the d projection of hv.c's dead
    time curve; prints conf0.r, hv0.drop_k and hv0.drop_knee. With r_known
    only V0 and the knee are fitted. Each new angle starts from 0 A for
    0.2 s, and after the first two dwells the current loop takes r from
    their slope (or r_known), so the steps do not overshoot.
    - l: a sine on d, then q, over the r test's bias: conf0.l and lq. It
    injects at the current loop's crossover, conf0.cur_bw / 2 pi
    (idpmsm0.loop_bw; 480 Hz at 3000), rounded to whole cycles per window;
    l_freq overrides it. A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
2026-10-23 vf: V/f on the shared angle with damping, stall prevention, encoder path
    vf is an open loop V/f drive on angle0 src 3, so hv0.vel is the
    synchronous speed and the f3 extrapolates the angle between packets. uf
    stays for existing configs.
    - Its own ramp (acc, dec); holds deceleration while the dc link is above
    dc_hold; a boost that fades out at boost_vel; the derate lowers the
    stall current.
    - Stall prevention on the active current (low passed at damp_hz):
    full acc up to i_stall, a hold at 1.1 * i_stall, backing off at up to
    stall_dec by 1.3 * i_stall.
    - Slip compensation from the low passed signed active current, right in
    reverse and when braking.
    - k_damp moves the field frequency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
2026-10-23 obs, sl_seq: shared flux observer and sensorless start for PMSM and ACIM
    - obs: PI phase locked loop on the back emf from voltage and current, in
    its own frame, so it can run as a shadow next to the encoder
    (obs_check template). It uses the sine of the error with the sign of
    rotation. r_w adds a d loss that grows with speed (induction motor
    iron loss), default 0. u_delay defaults to 0: the f3's voltage angle
    already leads by v_lead. The ACIM slip reaches vel_m through a copy of
    the tracking loop, so an iq step does not dip vel_m (that fed back into
    pid and rang at the observer bw on the spindle).
    - sl_seq aligns with i_f on d, runs I/f up to w_hand, hands angle0 to obs
    (src 2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
2026-10-23 acim_flux, angle, acim_fw, acim_foc: tr/lmr adaptation and saturation, FW feedforward, flux boost
    acim_flux (all new pins off by default):
    - tr_ki: tr adaptation from the reactive power residual
    (Q - Q_m) sign(w), within 0.5..2 x tr, gated by tr_iq_min, tr_vel_min,
    tr_flux_min and tr_acc_max.
    - tr_ks: tr from sl_seq0.slip_err in sensorless mode (Fanuc US8294411B2).
    - lmr_ki: lmr trim from the steady q voltage residual.
    - tr and lmr grow below rated flux (tr_sat, lmr_sat), stay at their
    plateau below i_knee, and fall below i_dip by lmr_dip.
    angle src 1 builds the field angle from the encoder angle plus integrated
    slip.
    acim_fw: flux feedforward scale_ff = duty_setpoint * pwm_volt /
    (|ve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
2026-10-23 idacim: leakage, tr and Lmr fit, V/f set, rotating flux sweep, inertia
    - l: injection on d at a pair either side of the current loop's
    crossover, 0.75 and 1.5 x conf0.cur_bw / 2 pi (idacim0.loop_bw;
    360/720 Hz at 3000), rounded to whole cycles per window;
    l^2 = (|Zb|^2 - |Za|^2) / (wb^2 - wa^2), stepping up an octave while
    w l is small. The cage's leakage falls with frequency (spindle: 0.93 mH
    at 120/240 Hz, 0.75 at 360/720), so l is measured in the loop's band.
    - Rotor test: d steps between test_cur and test_cur/2 at standstill; each
    edge fits lmr, tr and its own offset; lmr = median of the falling edges,
    tr = mean of the rising and falling medians. Spindle at 16 A: lmr
    13.0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
2026-10-23 F4 and F3 on CMSIS 5 and the Cube LL drivers; CubeIDE project; V3/F1 removed
    - CMSIS 5 core headers, STM32F3xx/F4xx device, system and startup files
    from STM32CubeF3/F4. newlib-nano on the f4 and the f3 (float printf
    and scanf kept), nosys.specs for the f4.
    - F4 app and bootloader on the STM32CubeF4 LL drivers; USB CDC on the
    Cube USB Device Library v2.11.4 over HAL PCD (SYSCFG clock enabled, D+
    held detached for 20 ms before connecting). The StdPeriph and old ST
    USB libraries are removed. Clock tree in f4_clock.c, shared by app and
    bootloader. Config save and hardboot program the flash on registers.
    enc_cmd and enc_fb use LL_TIM_ENCODER_Init. The resolver ADC trigger
    edge is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
2026-10-23 ringbuf, USB and the hv link: IRQ-safe ring, port-open gate, hv_update and link fixes
    - ringbuf: separate read and write positions, one slot free, safe
    between an IRQ and nrt; rb_getline drops a fragment that can never
    become a line and resyncs at the next '\n'.
    - f4 usb: every SETUP flushes EP0 IN; nothing is sent until the host
    opens the port (DTR or the first received byte), then 100 ms later.
    - hv_update: f3_boot skips pages that are already blank and the f4
    allows 12 s for the erase; CRC_CHECK is sent once and the f4 listens
    20 ms for the answer, repeating until 400 ms. hv_verify reads the f3
    app area back through the bootloader and compares it with the
    embedded image.
    - f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
2026-10-23 CubeMX reference .ioc files; conf template conf0.cur_bw 3000
    cubemx/ holds .ioc files for the F405 and F303 with the pinout, clock
    tree, peripheral modes, DMA and interrupt assignments the firmware sets
    up, for viewing and checking; the init code stays hand written. The F303
    PLL runs from HSE x 9 (72 MHz) as in periph.c. The 2017 pinout sketches
    in hw/kicad/v5.0/doc are removed.
    conf0.cur_bw 3000: on an alpha 3 axis the d-step rise is 0.8 ms at 3-10 A with at most
    1% overshoot.
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2026-10-23 id: iddac, idpmsm, idtune and idm fixes
    - iddac: a failure before the search starts restores dac_lo; the header
    and template give the real hv0.max_cur check.
    - idpmsm: clamp the psi speed loop integrator to test_cur; warn when the
    dead time knee lands on the grid edge and when dc_volt is unwired;
    check absolute feedback after the pp test; reset com_fb_offset/ok in
    state 0.
    - idtune: test convergence before the adv limits.
    - idm: pos_fb pin, the profile starts from the rotor position; state 13
    honours sys in the inertia clamp.
2026-10-23 sserial, linrev, hv_update, io4, siserial, smart_torque: link and review fixes, aged pos_fb
    - sserial: a bad crc packet is counted and the last good command kept
    for up to two in a row; a third sets error and zeroes the outputs
    until a good packet. The reply crc is written before the tx DMA starts.
    - linrev: rev counts fb_in's wraps and is taken from abs_rev only when
    the source becomes absolute or its count jumps by more than a turn;
    abs_neg negates abs_rev/abs_pos for the take (sserial templates link
    conf0.mot_fb_rev). rev_clear zeroes rev in absolute mode too.
    - hv_update: SEND_APP stops after the last word; FLASH_FAILED alternates
    a bootloader NOP with an app packet and retur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
2026-10-23 ids, idm, pid: id_pid search on conf0 limits, idm plateau fit, id_lpf; pid speed loop P term unclamped
    ids:
    - start values from conf0.pos_bw, vel_bw and vel_d (10 / 100 / 10 when
    0); a start that saturates is cut by kd and retried, up to CUT_MAX.
    - warm-up cycles after enable until pid stops saturating, up to
    WARM_MAX (25); the profile starts at pos_fb (fb_switch0.pos_fb).
    - each score averages rep cycles (default 2); cycles with pid0.sat or
    the torque at 0.99 x conf0.max_force are skipped (ids0.skipped).
    - a step fails when fb_torque above 50 Hz exceeds fb_max x max_torque
    rms; the torque peak is reported, not scored.
    - a raise is kept only while it cuts the cost by kg (0.05).
    - lim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
2026-10-23 pmsm_ttc: MTPA id/iq split behind pmsm_ttc0.mtpa (default off)
    With ld != lq the reluctance torque 1.5 p (ld - lq) id iq adds to the
    magnet's. mtpa 1 puts the torque command on the least current curve:
    id = (psi - sqrt(psi^2 + 4 dl^2 iq^2)) / (2 dl), dl = lq - ld, with iq from
    T = 1.5 p iq (psi - dl id), two fixed point passes from last tick's id.
    On an alpha 3 axis (psi 0.07057, dl 1.107 mH, pp 4) 16.3 A gives id -3.7 A and 3.0 %
    more torque than id 0, within 0.1 % of the exact optimum.
    pmsm_ttc0.id = id_in + the MTPA id; pmsm and mpmsm link id_in to
    fb_switch0.id and hv0.d_cmd to pmsm_ttc0.id, sl_pmsm its d_in, so with
    mtpa 0 (or lq 0) d_cmd is fb_switch0.id.
    - ld <= 0 counts as ld = lq: w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
2026-10-23 f3: power stage and link fixes from the component review, trip on the rated current
    io0:
    - a fault pin trip takes MOE off in the same tick, like the other
    software trips
    - the enable edge clears a break left from idle and re-arms the break
    irq, so an enable right after one is not reported as
    HV_OVERCURRENT_HW
    - the offset fault stays until reset
    - recon reads the compares through PWM_U/V/W
    - lo_u/v/w start long, so the first tick does not rebuild a phase
    ls0:
    - pwm_volt from io0.udc_duty, the link hv0 divides by
    - hv_temp_ok appended to the f3 state, hv0.hv_temp_ok on the f4 (an
    older f3 leaves it 0)
    - sbrake_time default in nrt_init, d/q targets and steps reset in
    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
2026-10-23 motion fixes: idx_home, ramp, home, fb_switch, vel_int, velbuf, veltopos, iit, pe, fault
    - sserial template links idx_home0.mot_state to fb_switch0.mot_state_fb
    (the input pin read 0, so index homing never completed); each request
    clears waitabs and lastq, so a later request waits for its own zero
    crossing.
    - ramp at_speed and the home exit work in both directions.
    - fb_switch: mot_joint_ratio defaults to 1 and applies in the absolute
    joint path; the plot shows pos_fb. The templates drop the nonexistent
    fb_switch0.joint_polecount lines.
    - vel_int detects edges per instance, velbuf's fallback spans 19
    periods, veltopos applies max_vel after the clamp; the velbuf template
    uses ve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
2026-10-23 comments: drop stale history notes, fix comments the code outgrew
    Comments only, no code change (checked per file with the comments
    stripped). Notes about earlier versions, commit hashes and dates are
    reworded to state the current design and its reason, or removed.
    Comments that no longer matched the code are corrected: ids no longer
    mentions pid's max_acc clamp, emf0's packet rate follows
    PWM_TICKS_PER_PACKET, the f3 ADC setup is in periph.c, periph.c's -O2,
    and the vf duty and idacim j_tv pin comments are back on their pins.
2026-10-23 enc_cmd: step/dir (mode 1) and dir/step (mode 2) on the CMD port
    TIM2 counts step edges in external clock mode 1; each dir edge captures
    the step count in hardware (CC2/CC1 on both edges), so the reversal step
    is exact whatever the interrupt latency. A TIM2 interrupt takes the
    captures and the rt takes any it finds pending. A lost dir edge (CCxOF)
    latches the new error pin, as does a mode the remap cannot do (up/down,
    or step modes on FB0/FB1). The template links fault0.cmd_error to it.
    Quadrature (mode 0) is unchanged.
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2026-10-23 tests/sim: host simulation harness for the F4 and F3 firmware
    The F4 hal and the F3 current loop compile on the host against a PMSM
    two-mass plant and an inverse-gamma induction motor plant (acim_flux's
    saturation shape, enc_fb0 encoder output, optional hv.c dead time curve;
    the flux curve is solved from the last step). Scenarios: Y moves and
    rings, spindle FOC on the encoder, in field weakening and sensorless,
    V/f open loop and encoder, idpmsm, id_mot and idacim against plants with
    known values (regression), FRF creep and two-mass fit (scen_frf, not in
    make test: 55-90 s each).
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2026-10-23 vel, vel_int, rev, sserial: velocity feedforward timing, acceleration feedforward from the host
    - vel.vel_p adds the tracking loop's proportional term to vel (the
    integrator alone trails the speed by 2 d / w in steady acceleration);
    vel_int.vel_ip extrapolates vel_out by the change of vel_in since the
    previous frame. Both default 0; fanuc_a3-3000 sets them 1. On an alpha 3 axis the
    drive ran ~38 um ahead of LinuxCNC through every acceleration; sim 50 mm
    at 750 mm/s2: steady error -32.4 -> 5.0 um.
    - vel_int0.acc_out: the per-frame change of vel_in, held until the next
    frame, 0 while the watchdog holds; acc_k scales it (0 = off), max_acc
    clamps it. rev gets in_dd/out_dd; the sser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
2026-10-23 flux_obs: hybrid rotor flux observer for the induction motor, slip trim
    Voltage model rotor flux in the stationary frame, blended (Jansen/Lorenz
    PI) onto the current model below wc (20 rad/s el), for the spindle on its
    encoder. It measures the orientation error of the current model (pos_err)
    without tr and optionally trims the slip: slip = slip_in * k + kp_s *
    pos_err, k = tr_model / tr_true learnt by ki_s, gated by speed, flux and
    slip; the kp term is bounded to 0.5 |slip_in| + slip_min and the output
    to acim_flux0.slip_max. Shadow by default (kp_s 0, ki_s 0); angle0.slip =
    flux_obs0.slip turns the trim on. Voltages are taken half an rt period
    behind the current's frame (u_adv 0 = -period /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
2026-10-23 dob: disturbance (load torque) observer on the torque command
    d = j dw/dt - u from a raw position-difference velocity, low passed at
    bw Hz, k * d subtracted from the torque. k 0 by default (estimate only); off while j <= 0 (the default), where it
    would cancel the drive's own torque command.
    Sim of an alpha 3 axis: load-step error 2.5-3x lower at bw 50-100 Hz, 200 Hz
    oscillates; on the axis: with the friction feedforward off, bw 50 halves
    the error. Not wired in any config.
    - dob estimates from the observer velocity: dob0.vel takes vel1.vel and
    differences it once, instead of the raw position twice (about 0.4 Nm
    rms on d_est at bw 50 with an 8000 count encoder). Harness alpha 3
    plant, 8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
2026-10-23 idacim: tr from the rotating ramps, flux sweep at constant emf, rotating tr check
    - Two pairs of up/down ramps (id_n and 0.65 id_n): tr from the air gap
    torque difference over the slip difference, slip from the encoder
    position (idacim0.pos_fb = fb_switch0.vel_fb); the second pair separates
    the field to position delay; prints acim_flux0.tr from the ramps. A slow
    trim holds id and iq on target so both ramps see the same current. The
    flux sweep runs after the ramps with their tr, each level at the ramps'
    top emf (up to rot_vmax of plate speed); tr per sweep point from the
    flux angle in the voltages over the encoder slip is reported; the knee
    fit prints acim_flux0.tr_dip (= lmr_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

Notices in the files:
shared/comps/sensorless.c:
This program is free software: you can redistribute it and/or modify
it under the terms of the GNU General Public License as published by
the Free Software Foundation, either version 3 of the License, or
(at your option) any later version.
